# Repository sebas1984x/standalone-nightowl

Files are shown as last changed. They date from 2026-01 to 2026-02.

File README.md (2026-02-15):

# Standalone NightOwl / ERB RP2040 Filament Switcher

Standalone firmware for a **NightOwl / ERB RP2040** filament switcher. ( https://github.com/mjonuschat/NightOwl )
This firmware runs **fully standalone** and does **not require Klipper integration**.  
The RP2040 handles filament loading, buffer-based feeding, and automatic lane swapping by itself.

Built for people who prefer firmware that *does the job* instead of having opinions.

---

## ✨ Features

- **2 filament lanes** (TMC2209 via STEP/DIR/EN)
- **Active-LOW switches** (C/NO to GND, internal pull-ups)
- Per lane:
  - IN switch (filament present)
  - OUT switch (preloaded / ready)
- **Filament buffer** Buffer logic uses latched hysteresis: feed starts at LOW and stops at HIGH.
- **Y-split switch** for swap safety
- **Autoload**
  - Insert filament → motor runs until OUT switch
- **Buffer-driven feed**
  - Feeds only when buffer LOW persists for a delay
- **Auto-swap**
  - Swap armed when active lane runs out
  - Swap executed when buffer requests feed and other lane is ready
- **Manual reverse buttons** (one per lane)
- **Potmeter-controlled feed rate**
- **Status LED** with multiple states
- **USB CDC debug output** (115200 baud)

---

## 🔧 Hardware assumptions

- All switches and buttons wired:
  - **Common + NO → GND**
  - Active when pulled LOW
- Internal pull-ups enabled in firmware
- Potmeter connected to **3.3V** ADC (**never 5V**)

---

## 📍 Pin Mapping

See:  
👉 [Pin Mapping](docs/pinout.md)

---

## 🔌 Wiring

See:  
👉 [Wiring Guide](docs/wiring.md)

---

## 🛠️ Build Instructions

### 1. Clone the Pico SDK
```bash
cd ~
git clone https://github.com/raspberrypi/pico-sdk.git
cd pico-sdk
git submodule update --init
```

### 2. Set the SDK path
```bash
export PICO_SDK_PATH=~/pico-sdk
```

(Optional, make permanent)
```bash
echo 'export PICO_SDK_PATH=~/pico-sdk' >> ~/.bashrc
source ~/.bashrc
```

### 3. Build the firmware (always clean)
```bash
cd ~/standalone-nightowl
rm -rf build
mkdir build
cd build
cmake ..
make -j4
```

After a successful build, this file must exist:
```
erb_standalone_mmu.elf
```

---

## 🔥 Flashing (FYSETC ERB – IMPORTANT)

⚠️ **The FYSETC ERB does NOT flash like a standard Raspberry Pi Pico.**  
Use this method or flashing will silently fail.

### Requirements
- Raspberry Pi (Pi 4 / Pi 5)
- `picotool` installed
- ERB connected via USB-C
- **24 V power connected to the ERB**

### Enter BOOTSEL / DFU mode
1. Power the ERB with **24 V**
2. Connect USB-C from ERB to the Pi
3. Hold **BOOTSEL**
4. Press **RST** for ~0.5 s
5. Release **RST**
6. Release **BOOTSEL after 2–3 seconds**

Verify:
```bash
lsusb
```

You must see:
```
2e8a:0003 Raspberry Pi RP2 Boot
```

### Flash
```bash
cd ~/standalone-nightowl/build
picotool load erb_standalone_mmu.elf -f
picotool reboot
```

➡️ The ERB will reboot and run the new firmware.

---

## 🖥️ Debug (USB CDC)

```bash
sudo screen /dev/ttyACM0 115200
```

Exit:
```
Ctrl-A → K → Y
```

---

## 🧪 Troubleshooting

See:  
👉 [Troubleshooting](docs/troubleshooting.md)

---

## 📄 License

MIT © sebas1984x

Use it, modify it, break it, improve it.  
Just don’t pretend you wrote it.

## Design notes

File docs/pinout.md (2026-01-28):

# Pin Mapping – ERB RP2040

All switch inputs are **active-LOW** with internal pull-ups enabled.

## Lane 1
- IN switch: GPIO24
- OUT switch: GPIO25
- Stepper EN: GPIO8
- Stepper DIR: GPIO9
- Stepper STEP: GPIO10

## Lane 2
- IN switch: GPIO22
- OUT switch: GPIO12
- Stepper EN: GPIO14
- Stepper DIR: GPIO15
- Stepper STEP: GPIO16

## Buffer
- Buffer LOW: GPIO6
- Buffer HIGH: GPIO7

## Y-split
- Y-split switch: GPIO2

## Manual reverse buttons
- Lane 1 reverse: GPIO28
- Lane 2 reverse: GPIO29

## Potmeter (feedrate)
- ADC pin: GPIO26 (ADC0)
- Voltage range: 0–3.3V ONLY

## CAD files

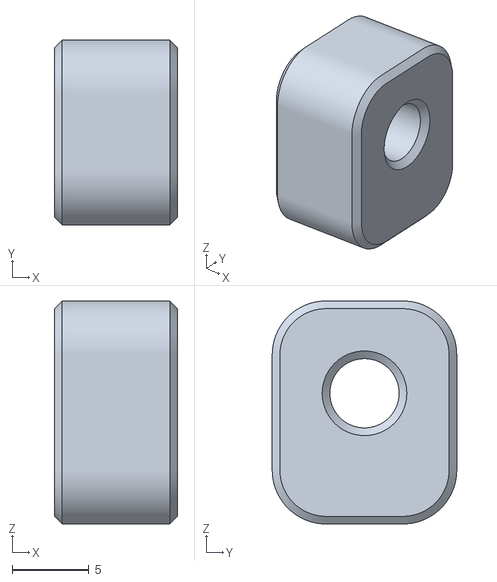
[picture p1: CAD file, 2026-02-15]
STL/Bowden_spring_mount.stl
8.00 x 12.0 x 14.5

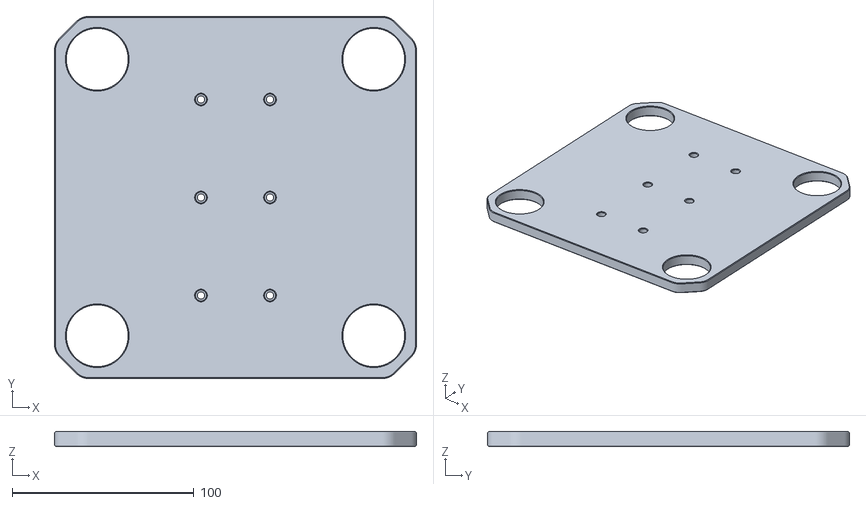
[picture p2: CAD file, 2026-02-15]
STL/nightowl_OSG mount_NightOwl v5_Body1.stl
199.2 x 199.2 x 8.00

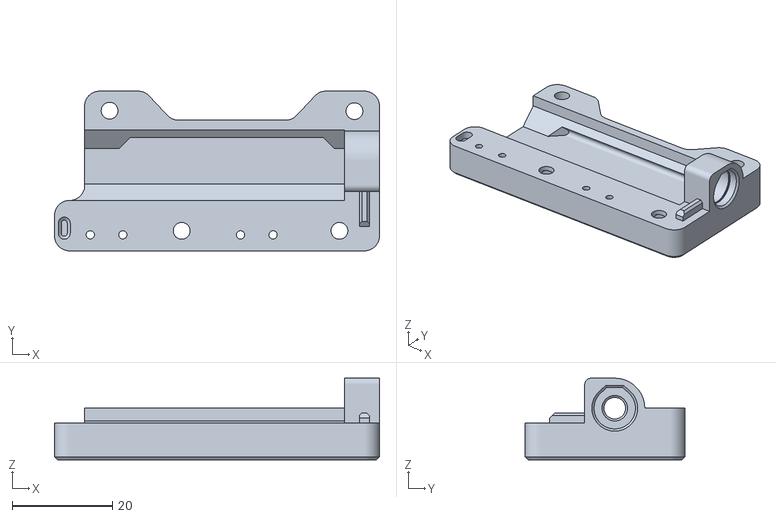
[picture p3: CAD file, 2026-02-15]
STL/TN_added spring mount.stl
64.9 x 31.9 x 16.3

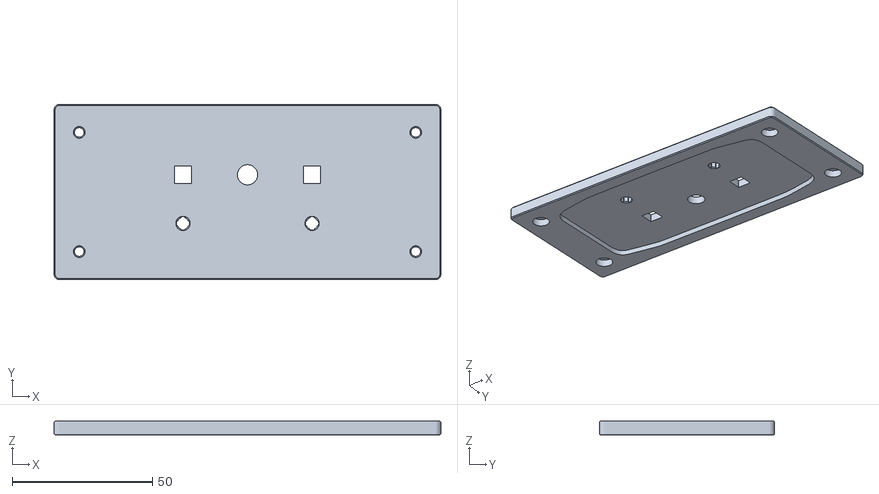
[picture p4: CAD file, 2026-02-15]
STL/Skirt (Front).stl
138.0 x 62.5 x 5.00

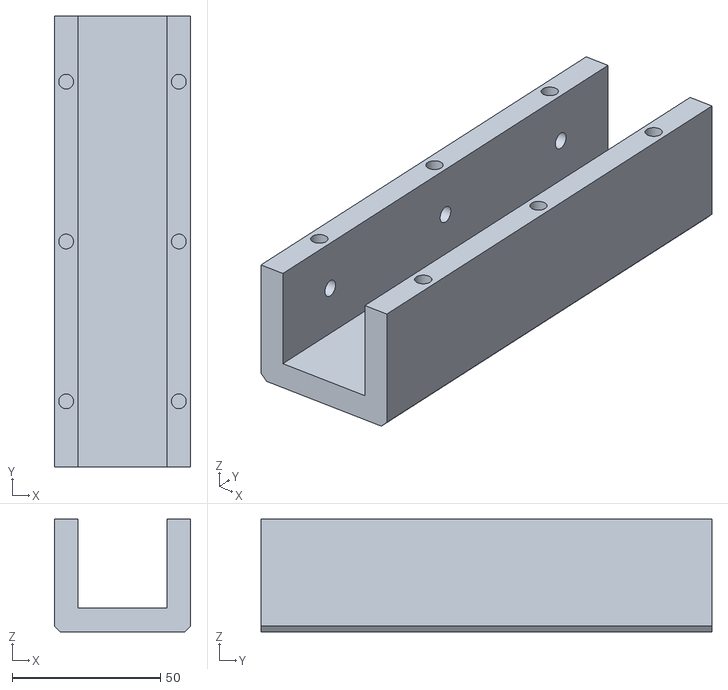
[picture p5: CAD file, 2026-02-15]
STL/nightowl_OSG mount_NightOwl v5_Body2.stl
46.0 x 152.2 x 38.0

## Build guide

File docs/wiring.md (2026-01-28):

# Wiring Guide – ERB RP2040

## Switches and Buttons
All switches and buttons are wired the same way:

- Common + NO -> GND
- Signal -> GPIO pin
- Active when pulled LOW
- Internal pull-ups enabled in firmware

No external resistors required.

## Potmeter (Feedrate Control)
Use a standard 3-pin potmeter (10k recommended).

- One outer pin -> 3.3V
- Other outer pin -> GND
- Middle pin (wiper) -> GPIO26 (ADC0)

⚠️ Never connect 5V to the ADC pin.

## Stepper Motors
Connect motors to the TMC2209 drivers as per the ERB board documentation.
Ensure:
- Correct motor coil pairing
- Shared ground between RP2040 and drivers

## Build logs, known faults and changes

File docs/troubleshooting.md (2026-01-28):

# Troubleshooting – ERB Standalone NightOwl

## Flashing does nothing
- Ensure the ERB is **really** in BOOTSEL mode
- Check `lsusb` for `2e8a:0003 Raspberry Pi RP2 Boot`
- 24V power must be connected during flashing

## Build fails
- Verify `PICO_SDK_PATH` is set
- Ensure pico-sdk submodules are initialized
- Clean build: remove `build/` and rebuild

## Potmeter has no effect
- Check wiring (wiper must go to GPIO26)
- Ensure ADC is powered from 3.3V
- Verify `ADC raw` changes in debug output

## Motors noisy or hot at low speed
- Avoid very low feed rates
- Increase minimum feed speed if needed
- Motor current may be set too high on the driver

## Nothing feeds
- Check buffer LOW/HIGH switch states
- Verify OUT switch is active on the selected lane
- Check debug output over USB

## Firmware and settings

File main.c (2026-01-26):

#include <stdio.h>
#include <stdbool.h>
#include <stdint.h>

#include "pico/stdlib.h"
#include "hardware/gpio.h"
#include "hardware/timer.h"
#include "hardware/adc.h"

/*
  Standalone NightOwl / ERB RP2040 firmware (2 lanes)
  - Buffer-driven feed + autoswap + autoload (non-blocking)
  - Manual reverse per lane (2 buttons)
  - Potmeter controls FEED rate (steps/sec)

  All switches/buttons wired C/NO to GND -> active LOW with pull-ups.
*/

// ---------------------------- CONFIG ----------------------------

// Switch pins (active low, pull-up)
#define PIN_L1_IN      24
#define PIN_L1_OUT     25
#define PIN_L2_IN      22
#define PIN_L2_OUT     12
#define PIN_Y_SPLIT    2
#define PIN_BUF_LOW    6
#define PIN_BUF_HIGH   7

// Manual REV buttons (active low, pull-up)
#define PIN_BTN_REV_L1  28
#define PIN_BTN_REV_L2  29

// Speed pot (ADC) -> FEED rate
#define USE_FEED_POT        1
#define PIN_POT_ADC_GPIO    26      // GPIO26 = ADC0
#define POT_ADC_CHANNEL     0
#define POT_READ_PERIOD_MS  50

// Feed rate range from pot (steps/sec)
#define FEED_SPS_MIN        1000
#define FEED_SPS_MAX        9000

// Manual reverse speed (fixed)
#define REV_STEPS_PER_SEC   4000

// Steppers
#define PIN_M1_EN      8
#define PIN_M1_DIR     9
#define PIN_M1_STEP    10
#define PIN_M2_EN      14
#define PIN_M2_DIR     15
#define PIN_M2_STEP    16

#define M1_DIR_INVERT  0
#define M2_DIR_INVERT  1
#define EN_ACTIVE_LOW  1

// Autoload speed (fixed)
#define AUTOLOAD_STEPS_PER_SEC  5000

// Timing
#define STEP_PULSE_US           3
#define LOW_DELAY_S             0.40f
#define SWAP_COOLDOWN_S         0.50f
#define AUTOLOAD_TIMEOUT_S      6.0f
#define DEBOUNCE_MS             10

#define REQUIRE_Y_CLEAR_FOR_SWAP  1

// Debug
#define DEBUG_PRINTS      1
#define DEBUG_PERIOD_US   500000

// Status LED (GPIO)
#define STATUS_LED_MODE   1
#define PIN_STATUS_LED    17
#define STATUS_LED_ACTIVE_HIGH 1

// Step catch-up guard: max pulses per loop per lane
#define STEP_CATCHUP_GUARD  50

// Main loop idle sleep (smaller => higher max step rate)
#define MAIN_LOOP_SLEEP_US  100

// -------------------------- END CONFIG --------------------------

static inline int clamp_i(int v, int lo, int hi) {
    if (v < lo) return lo;
    if (v > hi) return hi;
    return v;
}

// ------------------------ Debounced input -----------------------

typedef struct {
    uint pin;
    bool stable;
    bool last_raw;
    absolute_time_t last_edge;
} din_t;

static inline void din_init(din_t *d, uint pin) {
    d->pin = pin;
    gpio_init(pin);
    gpio_set_dir(pin, GPIO_IN);
    gpio_pull_up(pin);

    bool raw = gpio_get(pin);
    d->stable = raw;
    d->last_raw = raw;
    d->last_edge = get_absolute_time();
}

static inline void din_update(din_t *d) {
    absolute_time_t now = get_absolute_time();
    bool raw = gpio_get(d->pin);

    if (raw != d->last_raw) {
        d->last_raw = raw;
        d->last_edge = now;
    }

    if (raw != d->stable) {
        if (absolute_time_diff_us(d->last_edge, now) >= (int64_t)DEBOUNCE_MS * 1000) {
            d->stable = raw;
        }
    }
}

static inline bool active_low_on(const din_t *d) {
    return d->stable == 0;
}

// ---------------------------- Stepper ---------------------------

typedef struct {
    uint en, dir, step;
    bool dir_invert;
} stepper_t;

static inline void stepper_init(stepper_t *m, uint en, uint dir, uint step, bool dir_invert) {
    m->en = en; m->dir = dir; m->step = step; m->dir_invert = dir_invert;

    gpio_init(m->en);
    gpio_init(m->dir);
    gpio_init(m->step);

    gpio_set_dir(m->en, GPIO_OUT);
    gpio_set_dir(m->dir, GPIO_OUT);
    gpio_set_dir(m->step, GPIO_OUT);

    if (EN_ACTIVE_LOW) gpio_put(m->en, 1);
    else               gpio_put(m->en, 0);

    gpio_put(m->step, 0);
    gpio_put(m->dir, 0);
}

static inline void stepper_enable(stepper_t *m, bool on) {
    if (EN_ACTIVE_LOW) gpio_put(m->en, on ? 0 : 1);
    else               gpio_put(m->en, on ? 1 : 0);
}

static inline void stepper_set_dir(stepper_t *m, bool forward) {
    bool d = forward ^ m->dir_invert;
    gpio_put(m->dir, d ? 1 : 0);
}

static inline void stepper_pulse(stepper_t *m) {
    gpio_put(m->step, 1);
    sleep_us(STEP_PULSE_US);
    gpio_put(m->step, 0);
}

// ---------------------- Status LED layer ------------------------

typedef enum {
    LED_IDLE = 0,
    LED_FEEDING,
    LED_AUTOLOAD,
    LED_SWAP_ARMED,
    LED_MANUAL_REV,
    LED_ERROR
} led_state_t;

#if STATUS_LED_MODE == 1
static inline void status_led_init(void) {
    gpio_init(PIN_STATUS_LED);
    gpio_set_dir(PIN_STATUS_LED, GPIO_OUT);
    gpio_put(PIN_STATUS_LED, STATUS_LED_ACTIVE_HIGH ? 0 : 1);
}

static inline void status_led_put(bool on) {
    gpio_put(PIN_STATUS_LED, STATUS_LED_ACTIVE_HIGH ? (on ? 1 : 0) : (on ? 0 : 1));
}

static void status_led_update(led_state_t st, int64_t t_us) {
    bool on = false;
    switch (st) {
        case LED_IDLE: {
            int64_t phase = t_us % 1000000;
            on = (phase < 60000);
        } break;
        case LED_FEEDING:
            on = true;
            break;
        case LED_AUTOLOAD: {
            int64_t phase = t_us % 200000;
            on = (phase < 100000);
        } break;
        case LED_SWAP_ARMED: {
            int64_t phase = t_us % 1000000;
            on = (phase < 250000);
        } break;
        case LED_MANUAL_REV: {
            int64_t phase = t_us % 120000;
            on = (phase < 60000);
        } break;
        case LED_ERROR: {
            int64_t phase = t_us % 1200000;
            on = (phase < 80000) || (phase >= 160000 && phase < 240000);
        } break;
    }
    status_led_put(on);
}
#else
static inline void status_led_init(void) {}
static inline void status_led_update(led_state_t st, int64_t t_us) { (void)st; (void)t_us; }
#endif

// ---------------------------- Lane ------------------------------

typedef enum {
    TASK_IDLE = 0,
    TASK_AUTOLOAD,
    TASK_FEED,
    TASK_MANUAL
} task_mode_t;

typedef struct {
    din_t in_sw;
    din_t out_sw;
    stepper_t m;

    bool prev_in_present;

    task_mode_t mode;
    absolute_time_t next_step;
    absolute_time_t autoload_deadline;

    int steps_per_sec;
    bool forward;
} lane_t;

static inline bool lane_in_present(lane_t *L)  { return active_low_on(&L->in_sw); }
static inline bool lane_out_present(lane_t *L) { return active_low_on(&L->out_sw); }

static void lane_init(lane_t *L,
                      uint pin_in, uint pin_out,
                      uint pin_en, uint pin_dir, uint pin_step,
                      bool dir_invert) {
    din_init(&L->in_sw, pin_in);
    din_init(&L->out_sw, pin_out);
    stepper_init(&L->m, pin_en, pin_dir, pin_step, dir_invert);

    L->prev_in_present = false;
    L->mode = TASK_IDLE;
    L->next_step = get_absolute_time();
    L->autoload_deadline = get_absolute_time();
    L->steps_per_sec = 0;
    L->forward = true;
}

static inline int32_t step_interval_us(int sps) {
    if (sps <= 0) return 1000000;
    int32_t base = (int32_t)(1000000 / sps);
    int32_t adj  = base - (int32_t)STEP_PULSE_US;
    if (adj < 10) adj = 10;
    return adj;
}

static inline void lane_start_task(lane_t *L, task_mode_t mode, int sps, bool forward, float timeout_s) {
    L->mode = mode;
    L->steps_per_sec = sps;
    L->forward = forward;

    stepper_enable(&L->m, true);
    stepper_set_dir(&L->m, forward);

    // schedule first step "now"
    L->next_step = get_absolute_time();

    if (mode == TASK_AUTOLOAD && timeout_s > 0) {
        L->autoload_deadline = delayed_by_us(get_absolute_time(), (int64_t)(timeout_s * 1000000));
    }
}

static inline void lane_stop_task(lane_t *L) {
    L->mode = TASK_IDLE;
    stepper_enable(&L->m, false);
}

static void lane_update_inputs(lane_t *L) {
    din_update(&L->in_sw);
    din_update(&L->out_sw);
}

static void lane_process(lane_t *L) {
    // Stop conditions
    if (L->mode == TASK_AUTOLOAD) {
        if (lane_out_present(L) || time_reached(L->autoload_deadline)) {
            lane_stop_task(L);
            return;
        }
    }

    if (L->mode == TASK_IDLE) return;

    // Catch-up stepping: don't cap at one pulse per main loop
    int32_t interval = step_interval_us(L->steps_per_sec);

    int guard = 0;
    while (time_reached(L->next_step) && guard++ < STEP_CATCHUP_GUARD) {
        stepper_pulse(&L->m);

        // advance from scheduled time to keep timing stable even with jitter
        L->next_step = delayed_by_us(L->next_step, interval);
    }

    // If we hit the guard, we fell behind. Nudge schedule to "now" to avoid endless backlog.
    if (guard >= STEP_CATCHUP_GUARD) {
        L->next_step = get_absolute_time();
    }
}

// ------------------------ FEED pot (ADC) ------------------------

#if USE_FEED_POT
static void feed_pot_init(void) {
    adc_init();
    adc_gpio_init(PIN_POT_ADC_GPIO);
    adc_select_input(POT_ADC_CHANNEL);
}

static int feed_pot_read_sps(void) {
    uint16_t raw = adc_read(); // 0..4095
    int span = (FEED_SPS_MAX - FEED_SPS_MIN);
    int sps = FEED_SPS_MIN + (int)((raw * (uint32_t)span) / 4095u);
    return clamp_i(sps, FEED_SPS_MIN, FEED_SPS_MAX);
}
#endif

// ---------------------------- MAIN -----------------------------

#if DEBUG_PRINTS
  #define DBG_PRINTF(...) printf(__VA_ARGS__)
#else
  #define DBG_PRINTF(...) do{}while(0)
#endif

int main() {
    stdio_init_all();
    sleep_ms(1500);

    status_led_init();

#if USE_FEED_POT
    feed_pot_init();
#endif

    // Inputs
    din_t y_split, buf_low, buf_high;
    din_init(&y_split, PIN_Y_SPLIT);
    din_init(&buf_low, PIN_BUF_LOW);
    din_init(&buf_high, PIN_BUF_HIGH);

    // Manual buttons
    din_t btn_rev_l1, btn_rev_l2;
    din_init(&btn_rev_l1, PIN_BTN_REV_L1);
    din_init(&btn_rev_l2, PIN_BTN_REV_L2);

    // Lanes
    lane_t L1, L2;
    lane_init(&L1, PIN_L1_IN, PIN_L1_OUT, PIN_M1_EN, PIN_M1_DIR, PIN_M1_STEP, M1_DIR_INVERT);
    lane_init(&L2, PIN_L2_IN, PIN_L2_OUT, PIN_M2_EN, PIN_M2_DIR, PIN_M2_STEP, M2_DIR_INVERT);

    int active_lane = 1;
    bool swap_armed = false;

    absolute_time_t swap_cooldown_until = get_absolute_time();
    absolute_time_t low_since = get_absolute_time();

#if DEBUG_PRINTS
    absolute_time_t last_dbg = {0};
#endif

    // Pot throttling + live feed rate
    absolute_time_t next_pot_read = get_absolute_time();
    int feed_sps = 5000;

    while (true) {
        absolute_time_t now = get_absolute_time();
        int64_t t_us = to_us_since_boot(now);

        // Update inputs
        lane_update_inputs(&L1);
        lane_update_inputs(&L2);
        din_update(&y_split);
        din_update(&buf_low);
        din_update(&buf_high);
        din_update(&btn_rev_l1);
        din_update(&btn_rev_l2);

        bool l1_in_present  = lane_in_present(&L1);
        bool l2_in_present  = lane_in_present(&L2);
        bool l1_out_present = lane_out_present(&L1);
        bool l2_out_present = lane_out_present(&L2);

        bool buffer_low  = active_low_on(&buf_low);
        bool buffer_high = active_low_on(&buf_high);

        bool y_present = active_low_on(&y_split);
        bool y_clear = !y_present;

        bool rev_l1 = active_low_on(&btn_rev_l1);
        bool rev_l2 = active_low_on(&btn_rev_l2);
        bool any_manual = rev_l1 || rev_l2;

#if USE_FEED_POT
        if (time_reached(next_pot_read)) {
            next_pot_read = delayed_by_ms(now, POT_READ_PERIOD_MS);
            feed_sps = feed_pot_read_sps();
        }
#endif

        // ---------- Manual reverse per lane (fixed speed) ----------
        if (rev_l1) {
            if (L1.mode != TASK_MANUAL || L1.forward != false || L1.steps_per_sec != REV_STEPS_PER_SEC) {
                lane_start_task(&L1, TASK_MANUAL, REV_STEPS_PER_SEC, false, 0.0f);
            }
        } else if (L1.mode == TASK_MANUAL) {
            lane_stop_task(&L1);
        }

        if (rev_l2) {
            if (L2.mode != TASK_MANUAL || L2.forward != false || L2.steps_per_sec != REV_STEPS_PER_SEC) {
                lane_start_task(&L2, TASK_MANUAL, REV_STEPS_PER_SEC, false, 0.0f);
            }
        } else if (L2.mode == TASK_MANUAL) {
            lane_stop_task(&L2);
        }

        // ---------- Normal behavior (only if no manual) ----------
        if (!any_manual) {
            // Autoload on IN rising edge
            if (l1_in_present && !L1.prev_in_present && !l1_out_present && L1.mode == TASK_IDLE) {
                lane_start_task(&L1, TASK_AUTOLOAD, AUTOLOAD_STEPS_PER_SEC, true, AUTOLOAD_TIMEOUT_S);
            }
            if (l2_in_present && !L2.prev_in_present && !l2_out_present && L2.mode == TASK_IDLE) {
                lane_start_task(&L2, TASK_AUTOLOAD, AUTOLOAD_STEPS_PER_SEC, true, AUTOLOAD_TIMEOUT_S);
            }

            // Buffer hysteresis: need_feed when LOW persists and HIGH not active
            if (!buffer_low) low_since = now;
            bool low_persist = absolute_time_diff_us(low_since, now) > (int64_t)(LOW_DELAY_S * 1000000);
            bool need_feed = buffer_low && low_persist && !buffer_high;

            // Arm swap when active lane IN empty
            if (active_lane == 1 && !l1_in_present) swap_armed = true;
            if (active_lane == 2 && !l2_in_present) swap_armed = true;

            bool in_cooldown = !time_reached(swap_cooldown_until);

            // Execute swap
            bool allow_swap = need_feed && swap_armed;
#if REQUIRE_Y_CLEAR_FOR_SWAP
            allow_swap = allow_swap && y_clear;
#endif
            if (!in_cooldown && allow_swap) {
                if (active_lane == 1 && l2_out_present) {
                    active_lane = 2;
                    swap_armed = false;
                    swap_cooldown_until = delayed_by_ms(now, (int32_t)(SWAP_COOLDOWN_S * 1000));
                } else if (active_lane == 2 && l1_out_present) {
                    active_lane = 1;
                    swap_armed = false;
                    swap_cooldown_until = delayed_by_ms(now, (int32_t)(SWAP_COOLDOWN_S * 1000));
                }
            }

            // Feed management (pot controls feed_sps)
            lane_t *A = (active_lane == 1) ? &L1 : &L2;
            bool A_out_ok = (active_lane == 1) ? l1_out_present : l2_out_present;

            if (!in_cooldown && need_feed && A_out_ok) {
                if (A->mode == TASK_IDLE) {
                    lane_start_task(A, TASK_FEED, feed_sps, true, 0.0f);
                } else if (A->mode == TASK_FEED) {
                    A->steps_per_sec = feed_sps; // live update from pot
                }
            } else {
                if (A->mode == TASK_FEED) lane_stop_task(A);
            }
        } else {
            // Manual active: stop any auto-feed to avoid fighting
            if (L1.mode == TASK_FEED) lane_stop_task(&L1);
            if (L2.mode == TASK_FEED) lane_stop_task(&L2);
        }

        // Update prev flags
        L1.prev_in_present = l1_in_present;
        L2.prev_in_present = l2_in_present;

        // Process lanes (pulses + autoload stop)
        lane_process(&L1);
        lane_process(&L2);

        // LED
        led_state_t led = LED_IDLE;
        if (any_manual) led = LED_MANUAL_REV;
        else {
            if (swap_armed) led = LED_SWAP_ARMED;
            if (L1.mode == TASK_AUTOLOAD || L2.mode == TASK_AUTOLOAD) led = LED_AUTOLOAD;
            if (L1.mode == TASK_FEED || L2.mode == TASK_FEED) led = LED_FEEDING;
        }
        status_led_update(led, t_us);

#if DEBUG_PRINTS
        if (absolute_time_diff_us(last_dbg, now) > DEBUG_PERIOD_US) {
            last_dbg = now;
            DBG_PRINTF(
                "A=%d armed=%d man=%d feed_sps=%d  rev1=%d rev2=%d  "
                "l1[in=%d out=%d mode=%d]  l2[in=%d out=%d mode=%d]  "
                "y=%d yclr=%d  bufL=%d bufH=%d\n",
                active_lane, swap_armed, any_manual, feed_sps,
                rev_l1, rev_l2,
                l1_in_present, l1_out_present, (int)L1.mode,
                l2_in_present, l2_out_present, (int)L2.mode,
                y_present, y_clear,
                buffer_low, buffer_high
            );
        }
#endif

        sleep_us(MAIN_LOOP_SLEEP_US);
    }

    return 0;
}

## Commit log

2026-01-26 Update main.c added buttons
    added buttons and potmeter for reverse feed and speed adjustment
    [main.c]
2026-02-15 added custom parts
    [Bowden_spring_mount.stl, Skirt (Front).stl, TN_added spring mount.stl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]
